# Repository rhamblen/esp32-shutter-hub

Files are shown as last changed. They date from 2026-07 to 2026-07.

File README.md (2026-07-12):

# ESP32 Smart Shutter Hub

A compact, DIY smart-home controller that tilts existing internal plantation shutters with servo
actuators — behaving like a commercial product while staying small, cheap, mains-free (wired 5 V),
and fully local. One wall-mounted **hub** drives a configurable number of shutters (initially four
in the Front Room) and integrates natively with Apple Home and Home Assistant. Replaces a bulky
Zemismart JM36/JC601.

## Features

- **Hub architecture** — one ESP32 drives all shutters via a PCA9685; simple MG90D actuator modules.
- **Variable shutter count** — 1 to 4, by configuration only (no firmware change).
- **Apple HomeKit** — HomeSpan bridge exposes each shutter as its own Window Covering accessory.
- **Home Assistant** — one `cover.*` per shutter via MQTT discovery, plus lux/position sensors.
- **Local web UI** — control, per-shutter calibration, and OTA at `http://shutter-hub.local`.
- **Wiring at a glance** — an Info-page table of every device, its I²C bus, pins, address and channel.
- **Per-shutter calibration** — closed/open limits + named favourites (Privacy, Daylight) in µs.
- **Solar heat protection** — VEML7700 sunlight monitoring with configurable trip/clear thresholds.
- **Manual-override handling** — automation backs off for 2 h after a manual move.

## How it works

System architecture

One ESP32-D hub speaks to Apple Home (HomeSpan) and Home Assistant (MQTT) over WiFi, and drives the
servos through a PCA9685. A VEML7700 light sensor feeds the solar heat-protection logic. The number
of shutters is configuration, not code.

**Power & wiring**

Wiring schematic

**Actuator linkage**

Tilt linkage geometry

The tilt-rod drive is a four-bar linkage. **Build baseline (v0.9.2):** the owner's Zemismart-style
clip on the bottom slat is the crank; a tape-mounted MG90D on the rail's rear face → stock 20 mm
horn → M2×35 pushrod → clip pin drives all slats through 90°, everything hidden behind the panel
(rear pull-down). The servo cradle tapes on with no screws:

P1 servo cradle

Full kinematic analysis, an **animated simulator** (enter your shutter's measurements, get
collision/torque flags; v0.9.0–0.9.2 layouts are selectable presets), MG90D mount dimensions and
the 3D-print list live in the interactive design doc:
**<https://rhamblen.github.io/esp32-shutter-hub/tilt-linkage-design.html>**
(source: [docs/tilt-linkage-design.html](docs/tilt-linkage-design.html)).

**⬇ Download the 3D-print files** (right-click → Save, or just click — these are direct downloads):

| Part | 3MF | STL | Status |
| ---- | --- | --- | --- |
| P2 — slat-clip crank | [slat-clip-crank.3mf](https://github.com/rhamblen/esp32-shutter-hub/raw/main/cad/slat-hook/slat-clip-crank.3mf) | [slat-clip-crank.stl](https://github.com/rhamblen/esp32-shutter-hub/raw/main/cad/slat-hook/slat-clip-crank.stl) | ✅ ready — see [fitting notes](cad/slat-hook/README.md) |
| P1 — servo cradle | _pending_ | _pending_ | 📐 drawings only ([§7](https://rhamblen.github.io/esp32-shutter-hub/tilt-linkage-design.html)) |

Full parts list and print settings: **[cad/README.md](cad/README.md)**.

## Hardware (locked)

| Component | Choice | Default pins (ESP32-D) |
| --- | --- | --- |
| Controller | ESP32-D | — |
| Servo driver | PCA9685 (16-ch I2C, `0x40`) | `Wire` — SDA **GPIO21**, SCL **GPIO22** |
| Servos | MG90D digital metal-gear ×4 | PCA9685 **CH0–CH3** |
| Power | USB-C PD → AITRIP trigger (12 V) → XL4015 @ 5.1 V | — |
| Light sensor | VEML7700 (I2C, `0x10`) | `Wire1` — SDA **GPIO25**, SCL **GPIO26** |
| Linkage | M2 × 50 mm ball-link pushrod + printed arms | — |

By default the sensor sits on a **second, separate I2C bus** so a fault on its lead can never wedge
the servo bus ([ADR 0011](docs/decisions/0011-dedicated-sensor-i2c-bus.md)). It can also be told to
**share** the PCA9685's bus ([ADR 0012](docs/decisions/0012-selectable-sensor-i2c-bus.md)) — the only
option on chips with a single I2C controller, such as the ESP32-C3. Every pin above is
runtime-configurable and stored in NVS. Full map, including the ESP32-C3 proposal and the pins the
firmware rejects: **[docs/pinout.md](docs/pinout.md)**.

## Installation

Full step-by-step in **[docs/installation.md](docs/installation.md)**; everyday operation in
**[docs/user-guide.md](docs/user-guide.md)**. The short version:

1. **Flash once over USB.** Take the `esp32d-pca9685` assets from a
   [release](https://github.com/rhamblen/esp32-shutter-hub/releases) and write the `-full-` image to
   `0x0` plus the `-littlefs-` image — or build from source with
   `pio run -e esp32d-pca9685 -t upload && pio run -e esp32d-pca9685 -t uploadfs`.
   Flash the filesystem too; without it the hub serves only a bare OTA recovery page.
2. **Join your WiFi.** The hub raises a `Shutter-Hub-Setup` access point with a captive portal. Pick
   your 2.4 GHz network once — the credentials live in NVS and survive every future update.
3. **Open `http://shutter-hub.local`** and confirm a servo sweeps from the **Servo test** page.
4. **Define and calibrate each shutter** on the **Shutters** page: name it, assign its PCA9685
   channel, then set its closed/open endpoints and Daylight/Privacy favourites with the slow-run →
   stop → nudge transport. Everything else depends on this step.
5. **Point it at your MQTT broker** (**MQTT → Broker**, discovery on) and the covers, preset buttons
   and solar entities appear in Home Assistant by themselves. Optionally add the Lovelace card from
   [ha-card/](ha-card/), pair the HomeKit bridge from **System → HomeKit**, and set the trip/clear
   thresholds on the **Solar** page.

After the first flash every update goes over WiFi from the **OTA Update** page — settings,
calibration, and pairings are untouched.

## Status

**Current release `v0.7.2`.** In daily use: the web UI, per-shutter calibration, Home Assistant
control over MQTT, the Lovelace card, **Apple HomeKit pairing** (as of `v0.7.0`), and **solar heat
protection** driven by an ambient-light sensor. What's left for **v1.0.0** is the physical build-out —
enclosures, a PCB, and all four shutters mounted behind the wall (see the roadmap below).

Every shutter
defined in the web UI appears in HA as a native **`cover`** (open/close/stop + position 0–100) plus
six **`button`** entities (jog open/close, Daylight/Privacy recall + save) via MQTT discovery —
commands drive each shutter's own PCA9685 channel, **several simultaneously**, and retained
position/state topics track every move (web-UI moves included). The device interface is a
**LittleFS single-page app** (sidebar: Info · MQTT · Servo test · Shutters · System · OTA · Logs)
with a **live log stream** over WebSocket, a live per-shutter **MQTT topic map**, web
authentication, and a custom firmware+filesystem OTA updater. The servo backend is a **build
variant** — **direct GPIO** (one bench servo) or **PCA9685** (I2C multi-channel) — identified on
the Info/OTA screens and in the artifact names, with a persisted **speed slider** (5–120 °/s). The
**Shutters** page is per-blind calibration: a microsecond scrubber + transport controls (slow-run →
stop → frame-step nudge) set each blind's closed/open endpoints and Daylight/Privacy favourites,
all persisted in NVS. Servo positions are remembered across reboots/OTA so the first move slews
instead of snapping. A **Home Assistant Lovelace card** ([ha-card/](ha-card/)) gives a single tile
with group + per-shutter Open/Close/Daylight/Privacy and a manual position slider.
**Phase 5 (`v0.5.x`)** adds an **Apple HomeKit** bridge (HomeSpan): each shutter also appears in the
Home app as a **Window Covering**, configured on a new **System › HomeKit** tab (bridge name, setup
code, pairing QR). The bridge runs on its own task so it never interferes with servo control, and
reboot/OTA are driven by a reliable timer. **Status: working as of `v0.7.0`.** Pairing failed on the
author's hardware through v0.6.x; the root cause was finally found in v0.7.0 — HomeSpan 1.9.1's mDNS
hostname check uses a `sscanf("%m…")` conversion that **newlib-nano doesn't implement**, halting the
bridge before it advertised. With that patched, the bridge pairs and shutters **sync both ways**
(Home ↔ HA) — see [CHANGELOG.md](CHANGELOG.md).
**Phase 6 (`v0.6.0`)** adds **solar heat protection**: a **VEML7700** light sensor on its own I²C
bus drives a trip/clear state machine — when the sun stays above a threshold for a set dwell the
shutters move to a chosen preset, and a second threshold releases them. Both actions can be set to
**Do nothing**, a manual move suspends automation on that blind for 2 h, and a **simulate-lux
slider** lets the whole path be exercised from the Solar page. Lux, state, an automation switch and
two writable thresholds are published to Home Assistant.
**`v0.6.2`** makes the Info page a wiring check: a **Hardware & wiring** table naming every device,
its I²C bus (shared or dedicated), its pins, and its address or PCA9685 channel — plus HomeKit
status and a human-readable brightness percentage alongside raw lux.
**`v0.7.0`** makes **HomeKit pairing work** (see above), adds a bridge-health WARN watchdog, and
begins a log-level cleanup. Its fix is carried as a vendored HomeSpan patch under
[firmware/patches/](firmware/patches/). **`v0.7.1`** tidies that up — removes the investigation's
debug scaffolding and finishes the log-level cleanup (no behavioural change). **`v0.7.2`** fixes the
dashboard reading "not paired" after a reboot/OTA, and makes the servo-GPIO whitelist chip-aware so an
ESP32-C3 can no longer be configured onto a flash pin that bricks boot.
See [docs/project-plan.md](docs/project-plan.md) for the phased roadmap and [firmware/](firmware/)
to build/flash. Prebuilt bins ship on each
[release](https://github.com/rhamblen/esp32-shutter-hub/releases) — all four variants (ESP32-D, plus
ESP32-C3 as untested engineering builds): full (USB) and firmware (OTA), plus one shared LittleFS
filesystem image.

## Repo layout

| Path | Contents |
| ---- | --- |
| [docs/installation.md](docs/installation.md) | Full install guide — flash, WiFi, calibrate, HA, HomeKit, solar |
| [docs/user-guide.md](docs/user-guide.md) | Everyday operation, solar behaviour, recalibration, troubleshooting |
| [docs/pinout.md](docs/pinout.md) | GPIO map — ESP32-D defaults, ESP32-C3 proposal, rejected pins |
| [docs/project-brief.md](docs/project-brief.md) | Master engineering specification |
| [docs/project-plan.md](docs/project-plan.md) | Phased roadmap + status + open decisions |
| [docs/architecture.md](docs/architecture.md) | Principles, trade-offs, topology |
| [docs/inventory.md](docs/inventory.md) | Bill of materials + shutter facts |
| [docs/hardware-layout.md](docs/hardware-layout.md) | Breadboard build plan — placement, cuts, standoffs, cables |
| [docs/ha-lovelace-card.md](docs/ha-lovelace-card.md) | Lovelace card spec — entity model, config schema, layout |
| [docs/ai-context.md](docs/ai-context.md) | Cold-start map for the next AI session |
| [docs/decisions/](docs/decisions/) | Architecture Decision Records |
| [docs/diagrams/](docs/diagrams/) | Architecture, wiring, and linkage SVGs |
| [firmware/](firmware/) | ESP32 firmware (PlatformIO, Arduino Core) — build/flash/OTA |
| [ha-card/](ha-card/) | Home Assistant Lovelace operating card (custom element) |
| [hardware/](hardware/) | KiCad schematic / PCB + fabrication outputs |
| [cad/](cad/) | 3D-printer source + STL/STEP for enclosures & parts |
| [CHANGELOG.md](CHANGELOG.md) | Change history (Keep a Changelog + SemVer) |

## License & Legal

### License

This project is licensed under the MIT License — see the [`LICENSE`](LICENSE) file for details.

### Disclaimer

This is a DIY hardware project that drives mains-adjacent mechanical shutters with servos and a
custom power supply. **Use at your own risk** — you are responsible for the electrical safety and
mechanical integrity of anything you build from it. It is provided "as is", without warranty of any
kind. Apple Home integration is via the open-source [HomeSpan](https://github.com/HomeSpan/HomeSpan)
HomeKit library; this project is **not affiliated with, endorsed by, or condoned by Apple Inc.**

### Trademarks

- Apple, HomeKit, and Siri are trademarks of Apple Inc.
- ESP32 is a trademark of Espressif Systems (Shanghai) Co., Ltd.
- Home Assistant is a trademark of the Open Home Foundation.

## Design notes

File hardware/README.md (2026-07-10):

# Hardware — schematics & PCB

Circuit design source and fabrication outputs for the Shutter Hub.

## Contents

| File | Purpose |
| ---- | --- |
| `shutter-hub.kicad_sch` | KiCad schematic — complete ESP32-D circuit (power chain, I2C, servo driver, sensor) |
| `shutter-hub-schematic.svg` | Visual schematic — power chain, loads, wiring, critical build checklist |
| `shutter-hub-breadboard-layout.svg` | KiCad-style breadboard layout (plan view) — component placement, jumper/wire schedule W1–W13, connectors J1–J3, raised modules |

## Status

**Schematic complete** (`shutter-hub.kicad_sch`) for breadboard prototyping. **PCB layout and fabrication** are Phase 7. Currently, the working build is hand-wired on breadboard per Phases 1–6.

## Schematics & Drawings

Human-readable diagrams are in [`../docs/diagrams/`](../docs/diagrams/):

| Diagram | Purpose |
| --- | --- |
| [`wiring-schematic.svg`](../docs/diagrams/wiring-schematic.svg) | Power chain & signal routing (USB-C → XL4015 → ESP32-D, PCA9685, VEML7700) |
| [`system-architecture.svg`](../docs/diagrams/system-architecture.svg) | Overall hub architecture and component relationships |
| [`breadboard-plan.svg`](../docs/diagrams/breadboard-plan.svg) | Development breadboard layout (GPIO, I2C, power) |
| [`hub-build-overview.svg`](../docs/diagrams/hub-build-overview.svg) | Physical assembly and enclosure overview |
| [`standoff-mounting.svg`](../docs/diagrams/standoff-mounting.svg) | PCB mounting points and standoff placement |
| [`cable-loom.svg`](../docs/diagrams/cable-loom.svg) | Servo rail and sensor cabling layout |
| [`rail-cuts-bridges.svg`](../docs/diagrams/rail-cuts-bridges.svg) | Servo power rail distribution |

See [`../docs/hardware-layout.md`](../docs/hardware-layout.md) for detailed component placement and [`../docs/pinout.md`](../docs/pinout.md) for GPIO/I2C pin mapping.

## Design intent (see `../docs/project-brief.md` §3–4)

```
USB-C PD → AITRIP trigger (12 V) → XL4015 (5.1 V) ─┬─ ESP32-D VIN
                                                   ├─ PCA9685 V+
                                                   └─ servo rail (+1000–2200 µF) → MG90D ×N
ESP32-D I2C (GPIO21 SDA / GPIO22 SCL) ─┬─ PCA9685 (0x40) → CH0..CHn
                                       └─ VEML7700 (0x10)
Single-point common ground.
```

Design rules to honour on the PCB: keep the servo-power copper wide (2–3 A), place the bulk
capacitor next to the PCA9685 V+, keep the ESP32 rail decoupled from servo current, and leave
airflow / vent area over the XL4015 (see [ADR 0003](../docs/decisions/0003-power-chain-xl4015-pca9685.md)).

> Status: **to be produced.** A hand-wired/protoboard build (Phases 1–6) precedes the PCB
> (Phase 7). Until then this folder holds the wiring diagram only.

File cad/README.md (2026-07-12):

# CAD — 3D-printed parts

Enclosures and mechanical parts for the hub and the per-shutter actuator modules.

## ⬇ Download print files

Direct download links (click to save — no GitHub account needed). Both `.3mf` (with print
metadata) and `.stl` are provided for each ready part.

| Part | 3MF | STL | Status |
| ---- | --- | --- | --- |
| **P2 — slat-clip crank** | [⬇ .3mf](https://github.com/rhamblen/esp32-shutter-hub/raw/main/cad/slat-hook/slat-clip-crank.3mf) | [⬇ .stl](https://github.com/rhamblen/esp32-shutter-hub/raw/main/cad/slat-hook/slat-clip-crank.stl) | ✅ ready to print |
| **P1 — servo cradle** | _pending_ | _pending_ | 📐 drawings only ([servo-cradle-p1.svg](../docs/diagrams/servo-cradle-p1.svg)) |

> Tip: on the GitHub file page for any part, the **Download raw file** button (top-right ⬇ icon)
> saves it too. To grab everything at once, use the green **Code → Download ZIP** on the repo home.

## Contents (as produced)

| Path | Part | Notes |
| ---- | ---- | ----- |
| `hub-enclosure/` | Wall-mounted hub box | Compartments for AITRIP trigger, XL4015 (vent slots above), ESP32-D, PCA9685; servo-cable exits; VEML7700 light window |
| `actuator-module/` | P1 — servo cradle (**tape-mount, drawings done; 3MF pending**) | MG90D case bonded in with a 2nd VHB strip (no screws, tabs unused); plate 40×34×2.4 VHB'd to the rail rear face; side walls stop short of the tabs; 4 mm cable gallery + open lay-in slot. Axis (+24.7,−49). Drawings: [servo-cradle-p1.svg](../docs/diagrams/servo-cradle-p1.svg) · design doc §7 |
| `slat-hook/` | P2 — slat-clip crank (**produced**: `slat-clip-crank.3mf`) | Zemismart-style sleeve clip + added drill boss; wedges onto the 8 mm slat, M2 ball stud drilled 12 mm from the rear edge → pin 26.6 mm @ −16°; see [slat-hook/README.md](slat-hook/README.md) |
| `servo-arm/` | P3 — 22 mm servo arm (optional) | Only for the 34 mm-crank torque variant; stock 20 mm horn is the baseline |
| `servo-test-bracket/` | Phase 0 proving rig | Temporary mount to run the force test |

Each part folder holds **editable source** (FreeCAD `.FCStd` / Fusion `.f3d` / OpenSCAD `.scad`)
**and** exported **`.stl`** (print-ready) plus **`.step`** (interchange). Keep source + exports
together so the parts stay editable.

## Key dimensions (see `../docs/tilt-linkage-design.html` — interactive design doc)

- Servo: MG90D case 22.8 × 12.2 × 28.5 mm; tabs 32.5 mm span, Ø2.2 holes @ 27.5 mm centres;
  shaft axis ≈6 mm from the front face; 21T Ø4.8 spline. Verify with calipers — clones vary ±0.3 mm.
- Linkage (v0.9.1 four-bar): stock 20 mm horn + **front-edge** slat hook (pin 24 mm on the
  front-edge line; 06:00 closed → 03:00 open) + **M2×25** ball-link pushrod at **46 mm**
  hole-to-hole. ~114° servo sweep → 90° slat travel, jam margin 11.3 mm, torque ratio ≤0.85.
- **Build baseline (v0.9.2):** the owner's clip drives a **rear pull-down** layout — servo cradle
  tape-mounted on the rail's rear face, axis **(+24.7, −49)**, stock 20 mm horn, M2×35 pushrod at
  58 mm, clip pin 26.6 @ −16°. ~132° sweep, jam margin 9.3 mm, ratio ≤0.77, rear-most 44.7 mm.
  (v0.9.0/0.9.1 variants retained in the design doc as presets.)
- Shutter geometry: frame/rail thickness **28 mm (measured)**; still to measure: rocker radius
  R ≈ 36 mm, slat pitch ≈ 63 mm, rail top ≈ 45 mm below the bottom pivot, rear depth ≥ 43 mm.

[`../docs/diagrams/linkage-geometry.svg`](../docs/diagrams/linkage-geometry.svg) shows the
three-pose geometry (closed / mid / open), generated from the same solver. The HTML design doc is
authoritative and served live at
<https://rhamblen.github.io/esp32-shutter-hub/tilt-linkage-design.html>.

> Status: **to be produced.** Phase 0 prints the servo-test-bracket + shutter-arm first; final
> enclosures come in Phase 7.

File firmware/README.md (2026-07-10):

# Firmware — ESP32 Smart Shutter Hub

PlatformIO project (Arduino Core, `esp32dev`). Structural reference:
[HomeKey-ESP32](https://github.com/rednblkx/HomeKey-ESP32). See
[../docs/project-plan.md](../docs/project-plan.md) for the phased roadmap.

## What this version does (v0.7.2)

On-device WiFi setup, advertises `shutter-hub.local` over mDNS, and serves a
**single-page web UI from LittleFS** (sidebar: Info · MQTT · Servo test · Shutters ·
Solar · System · OTA · Logs) over a JSON/REST API. A **live log stream** runs over
WebSocket (`/ws/logs`). The **Info** page carries a **Hardware & wiring** table (v0.6.2)
— every device, its I²C bus, pins, and address or channel — a read-only mirror of
settings made on the other pages. **MQTT (Phase 4)**: every shutter defined on the Shutters page becomes a
native **Home Assistant `cover`** (open/close/stop + position 0–100) plus **six
`button` entities** (jog open/close, Daylight/Privacy recall, save Daylight/Privacy)
via MQTT discovery — commands drive each shutter's own PCA9685 channel, **several
simultaneously** (ADR 0010), and retained `position`/`state` topics track every move,
web-UI ones included. The MQTT page's **Topics** tab shows the live per-shutter topic
map. Custom **OTA** flashes firmware and/or the LittleFS image. The **Servo test** page
is a low-level bench diagnostic with a persisted **speed slider** (5–120 °/s); the
**Shutters** page (Phase 2) is per-blind **calibration**: a microsecond scrubber +
transport controls (slow-run → stop → frame-step nudge) snapshot each blind's
closed/open endpoints and Daylight/Privacy favourites, all persisted in NVS (survives a
filesystem OTA). The servo backend is a **build variant** — `-direct` (one servo off a
GPIO, bare ESP32) or `-pca9685` (I2C multi-channel); the web UI adapts to whichever
it's running.

**Solar heat protection (Phase 6, v0.6.0–v0.6.2)**: a **VEML7700** drives a trip/clear
state machine that moves the shutters to a chosen preset in strong sun. Its I²C bus is a
setting — its own `Wire1` (default) or shared with the PCA9685 (ADR 0011/0012). The
**Solar** page has a **simulate-lux slider**, so the whole feature is exercisable with no
sensor fitted. Lux, a 0–100 % brightness figure, solar state, an automation switch and two
writable lux thresholds are published to Home Assistant.

**Apple HomeKit (Phase 5, v0.5.x–v0.7.2)**: a HomeSpan bridge exposes each shutter as a Window
Covering, configured under **System → HomeKit**. It runs on its own FreeRTOS task, so HAP
never stalls the servo loop. **Pairing works** (fixed v0.7.0 — HomeSpan 1.9.1's `sscanf("%m…")`
hostname check isn't supported by newlib-nano; patched under [`patches/`](patches/)). The bridge
is discovered, pairs, and syncs both ways with Home Assistant. See
[../docs/project-plan.md](../docs/project-plan.md) Phase 5.

## WiFi setup (on-device — no credentials in the binary)

On first boot (and after **Change WiFi**) the hub becomes an access point
**`Shutter-Hub-Setup`** with a captive portal:

1. Join the `Shutter-Hub-Setup` network from a phone or laptop.
2. The captive portal opens (or browse to `http://192.168.4.1`). Pick your WiFi
   and enter the password.
3. The hub saves the credentials to **NVS** and reconnects. NVS is a separate
   flash partition, so the credentials **survive OTA updates** — you only do this
   once.

This uses [WiFiManager](https://github.com/tzapu/WiFiManager) — the Arduino-native
version of the SoftAP + captive-portal pattern in
[HomeKey-ESP32](https://github.com/rednblkx/HomeKey-ESP32). Because nothing is
compiled in, the same prebuilt bin works on anyone's network. To change networks
later, use **System → WiFi** (scan/connect in place); **Reset WiFi** in the System
page's Quick Actions reboots back into this setup portal.

## Build

From **v0.3.0** the firmware ships as **variants** = *board × servo backend* (see
[../docs/decisions/0008-build-variants.md](../docs/decisions/0008-build-variants.md)).
Each variant is a PlatformIO env carrying a `FW_VARIANT` id that shows on the
Dashboard/OTA screens and names the artifacts:

| Env | Board | Servo backend | Status |
| --- | ----- | --- | --- |
| `esp32d-direct` | ESP32-D | direct GPIO (ESP32Servo) | active |
| `esp32d-pca9685` | ESP32-D | PCA9685 I2C (Adafruit PWM) | **active, default** |
| `esp32c3-direct` | ESP32-C3 | direct GPIO | deferred |
| `esp32c3-pca9685` | ESP32-C3 | PCA9685 I2C | deferred |

```
pio run                            # builds the default env (esp32d-pca9685)
pio run -e esp32d-direct           # ESP32-D, direct-GPIO servo
pio run -e esp32d-pca9685          # ESP32-D, PCA9685
pio run -e esp32c3-pca9685         # ESP32-C3 (deferred; build explicitly if needed)
```

Prebuilt bins are collected in [`dist/`](dist/). From **v0.2.0** a release ships
**three bins per variant** (the web UI now lives in `data/`):

| Scope | File | Use | Since |
| ----- | ---- | --- | ----- |
| Per variant | `shutter-hub-<variant>-full-vX.Y.Z.bin` | first USB flash, merged at `0x0` | now |
| Per variant | `shutter-hub-<variant>-ota-vX.Y.Z.bin` | OTA page → **Upload Firmware** | now |
| Per **board** | `shutter-hub-esp32d-littlefs-vX.Y.Z.bin` | OTA page → **Upload LittleFS** | **v0.2.0** |

Build the filesystem image with `pio run -e <variant> -t buildfs` →
`.pio/build/<variant>/littlefs.bin`. **Flash it alongside the firmware** — without it
the device serves an embedded recovery page (OTA upload only). The LittleFS image is
**identical across variants** (the Servo-test page adapts at runtime), so one filesystem
bin per version is enough — only the firmware differs per variant.

_ESP32-C3 bins are not built or released yet._

## First flash (USB — one time only)

After this, every update goes over WiFi (see OTA below).

**Option A — PlatformIO, board on USB:**
```
pio run -e esp32d-pca9685 -t upload   # auto-detects the port; monitor with:  pio device monitor
```

**Option B — single merged image (NodeMCU-PyFlasher / esptool):**
Flash the `-full-` image for your variant at offset `0x0`:
```
esptool --chip esp32 write_flash 0x0 dist/shutter-hub-esp32d-pca9685-full-v0.7.2.bin
```
In NodeMCU-PyFlasher: select the `...-full-...bin`, address `0x0`, flash.

> Merge recipe (how the `-full-` image is made): `esptool --chip esp32 merge-bin`
> with bootloader + partitions + boot_app0 + firmware. The ESP32-D bootloader sits at
> `0x1000` and the app at `0x10000`.

## Update over the air (every time after the first)

The **OTA Update** page at `http://shutter-hub.local/` is a custom updater: it shows the
installed version, chip, last flash, and two uploaders — **Firmware** and
**Filesystem (LittleFS)** — with an upload log.

1. Build new bins: `pio run` (firmware) and `pio run -t buildfs` (filesystem).
2. **Upload Firmware** with the app bin; **Upload LittleFS** when the web UI (`data/`)
   changed. Upload the filesystem first if both changed, then the firmware (which reboots).
3. The board reboots into the new build — your saved WiFi and settings are untouched
   (they live in NVS, not the app/filesystem partitions).

## Layout

```
firmware/
├─ platformio.ini              board targets + libraries + build flags
├─ include/                    module headers (*.h)
├─ data/                       LittleFS web UI (index.html, style.css, app.js, qrcode.min.js)
├─ src/
│  ├─ main.cpp                 thin entry point — wires the modules together
│  ├─ AppConfig.cpp            persisted settings: device, servo, MQTT, auth, HomeKit, solar (NVS)
│  ├─ Diagnostics.cpp          logging + log ring buffer + WS sink, /info
│  ├─ WiFiSetup.cpp            WiFiManager AP + captive portal
│  ├─ WebUI.cpp                static SPA + JSON API + /ws/logs + mDNS
│  ├─ Ota.cpp                  custom firmware + LittleFS OTA
│  ├─ ServoController.cpp      multi-slot µs driver, backend = GPIO | PCA9685
│  ├─ Shutters.cpp             per-blind definitions + calibration (NVS)      [Phase 2]
│  ├─ Mqtt.cpp                 HA covers/buttons/solar + discovery + state    [Phase 4/6]
│  ├─ HomeKit.cpp              HomeSpan bridge (pairing works)                [Phase 5]
│  ├─ LightSensor.cpp          VEML7700 driver (selectable I²C bus)           [Phase 6]
│  └─ SolarLogic.cpp           trip/clear state machine + manual override     [Phase 6]
├─ dist/                       prebuilt release artifacts (bins gitignored; attached to releases)
└─ README.md
```

The web UI is static files in `data/` (LittleFS), served by `WebUI` over a JSON API +
WebSocket; the firmware falls back to an embedded recovery page if the FS image is
missing (see ADR 0004/0005). `WebUI` is named that (not `WebServer`) to avoid clashing
with the Arduino core's `WebServer.h` that WiFiManager includes.

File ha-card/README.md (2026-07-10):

# shutter-hub-card — Home Assistant Lovelace card

An operating tile for the ESP32 Shutter Hub: 1–6 named shutters side by side, the four
blind states (**Open · Close · Daylight · Privacy**) and a **manual position slider**,
applied to **all shutters at once** or to **one selected shutter**.

No build step — a single plain custom element (`shutter-hub-card.js`), registered as a
Lovelace resource. Full design rationale in
[../docs/ha-lovelace-card.md](../docs/ha-lovelace-card.md) and
[../docs/decisions/0007-ha-lovelace-card.md](../docs/decisions/0007-ha-lovelace-card.md).

## What it does

- **Group mode (default)** — every configured shutter shown as a tile (a slat glyph whose
  angle tracks position, its name, and state). The button bar and slider act on **all**
  shutters.
- **Individual mode** — tap a tile to scope the buttons and slider to just that shutter;
  tap it again, or **Select all**, to return to the group.
- **Four states** — Open / Close drive the cover to its calibrated limits; Daylight /
  Privacy press the saved-preset buttons.
- **Manual position** — the slider commands an arbitrary position (0–100 %) via
  `cover.set_cover_position`, for any angle that isn't one of the four presets.
- **Stop** — halts an in-flight move.

## Entities

Binds to the MQTT-discovered entities (one hub device):

| Entity | Role |
| --- | ---- |
| `cover.<hub>_<id>` | open / close / stop / position |
| `button.<hub>_<id>_daylight` | recall the saved Daylight preset |
| `button.<hub>_<id>_privacy` | recall the saved Privacy preset |

The two button ids default to the cover id with `cover.` → `button.` and a
`_daylight` / `_privacy` suffix; override per shutter with `daylight:` / `privacy:` if
your naming differs.

### Solar heat protection (optional)

If the hub has a VEML7700 fitted, three more entities can be bound. Supply any of them and the
group header grows a **live light caption** and an **automation toggle**; omit them all and the
card renders exactly as before, so no-sensor installs are unaffected.

| Config key | Entity | Role |
| --- | --- | ---- |
| `solar_switch` | `switch.<hub>_solar_automation` | Turns the trip/clear automation on or off |
| `solar_lux` | `sensor.<hub>_light_level` | Raw illuminance in lux — what the card's caption shows |
| `solar_state` | `sensor.<hub>_solar_state` | `idle` · `counting-trip` · `tripped` · `counting-clear` |

**Why the caption reads lux and not a percentage.** The hub also publishes
`sensor.<hub>_brightness` (0–100 %), which is friendlier to read but is **display-only**, and this
card does not use it. It is a logarithmic restatement of the same reading —
`20 × log10(lux)`, one lux decade per 20 points:

| Brightness | Lux | Roughly |
| --- | --- | --- |
| 0 % | 1 | dark room |
| 20 % | 10 | dim |
| 40 % | 100 | lit room |
| 54 % | ~500 | bright room |
| 60 % | 1 000 | overcast, by a window |
| 80 % | 10 000 | overcast daylight |
| 100 % | 100 000 | full sun |

A linear percentage of the sensor's 120 000 lx full scale was rejected: it reads 0 % at every
indoor level and only moves in direct sun. The log curve fixes that, but it compresses the
30 000–60 000 lx band where the trip and clear thresholds live — the defaults land at 96 % and
90 %, six points apart — so it can't be used to set or reason about thresholds, and it isn't
cleanly invertible. **The state machine trips on raw lux**; raw lux is what the caption shows and
what Home Assistant's long-term statistics record. Treat brightness as a human-readable gauge,
never as an automation input.

```yaml
solar_switch: switch.shutter_hub_solar_automation
solar_lux: sensor.shutter_hub_light_level
solar_state: sensor.shutter_hub_solar_state
```

## Install

Two paths — both end with the same dashboard card.

**Inline resource (what this repo deploys):** register `shutter-hub-card.js` as a
dashboard resource of type `module` (the HA config API accepts inline module content), then
add the card below. No file hosting needed.

**Filesystem:** copy `shutter-hub-card.js` to `/config/www/shutter-hub-card.js`, add a
Lovelace resource `URL /local/shutter-hub-card.js`, type **JavaScript Module**, hard-refresh.

## Card config

```yaml
type: custom:shutter-hub-card
title: Shutters
shutters:                       # 1–6 entries, order = display order
  - entity: cover.shutter_hub_shutter_1
    name: Left                  # optional; defaults to the cover's friendly name
  - entity: cover.shutter_hub_shutter_2
    name: Right
```

## Not included (Phase 8, optional)

**Calibration / config card** — setting raw-µs positions, the full-open/close travel
endpoints, and *saving* into the four slots — is deliberately a **separate card**, planned
as **optional Phase 8** in [the project plan](../docs/project-plan.md). It needs firmware
commands that don't exist yet (an absolute *go-to-µs*, raw-µs readback, and `save:open` /
`save:close`), documented in [../docs/ha-lovelace-card.md](../docs/ha-lovelace-card.md) §4.
Until then, calibrate in the hub's web UI; this card operates the shutters HA already
knows how to drive.

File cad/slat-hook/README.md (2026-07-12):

# P2 — slat-clip crank

**⬇ Download:** [slat-clip-crank.3mf](https://github.com/rhamblen/esp32-shutter-hub/raw/main/cad/slat-hook/slat-clip-crank.3mf)
· [slat-clip-crank.stl](https://github.com/rhamblen/esp32-shutter-hub/raw/main/cad/slat-hook/slat-clip-crank.stl)
(identical geometry; use whichever your slicer prefers)

The Zemismart-style rod-to-slat coupler (`clip1.3mf`) with a **solid drill boss** added under the
bottom strap. Clipped onto the bottom slat it becomes the linkage's crank; an M2 ball-stud through
the boss is the drive pin. Two closed shells in one object — every slicer unions them.

## How the original part works (measured from the mesh)

- **Sleeve**: mouth 8.35 mm, ~67 mm deep, tapering toward a solid nose. An 8 mm slat wedges tight
  where the taper reaches 8.0 (≈12 mm short of the nose) — the taper *is* the retention, so the
  geometry is left untouched.
- **Fin jaw** (5.0 mm gap): factory feature that snaps onto the tilt-rod bar. **Unused here** — the
  clip must sit ≥10 mm inboard of the rod's plane. Leave it or trim it.
- 12 mm wide along the slat; straps 1.35 / 1.75 mm thick.

## Fitting (rear pull-down layout)

1. Push the clip onto the bottom slat **from the rear (window) edge**, ≥10 mm inboard of the
   tilt-rod staple, until it wedges. Nose ends up near the rear edge, fin at the front.
2. Mark the boss **12 mm in from the slat's rear edge**, at the boss's mid-height.
3. Drill Ø1.8 through the boss along the slat direction; fit the M2 ball stud (self-tap), ball on
   the side facing the servo.

Ball centre lands ≈ **26.6 mm radius, −16° phase** from the slat pivot.

## Matching linkage (solved for this pin; slats close rear-edge-up)

| Element | Value |
| --- | ----- |
| Servo arm | stock **20 mm** horn |
| Pushrod | **M2×35 at 58 mm** hole-to-hole (any owned rod 46–61 works — drop the servo 1 mm per 1 mm of extra rod) |
| Servo axis | **(+21, −49)** from the bottom slat pivot — cradle on the rail's rear face, 1 mm plate |
| Sweep | ~129° of 180° → 90° slat travel, near-linear |
| Jam margin / torque | 9.9 mm / ratio ≤0.79 → ≈2.8 kg·cm at the slats |
| Envelope | x ∈ [+7, +41] — fully behind the panel, nothing on the room side |

Verify against your measurements in the live simulator (crank 26.6 / phase −16):
<https://rhamblen.github.io/esp32-shutter-hub/tilt-linkage-design.html>

## Load-path note

The clip was designed to be dragged by the rod, not to drive the slat. If it slips on the slat
under torque, add two grub-screw dimples through the straps or a drop of silicone in the sleeve.

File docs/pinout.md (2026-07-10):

# Pinout Summary

Every GPIO the hub uses, per board. The **ESP32-D** table is authoritative — it is what the firmware
actually defaults to today. The **ESP32-C3** table is a *proposal*: the C3 build variants compile,
but their pin map has never been revisited and a hardware limit still blocks them. See
[C3 status](#esp32-c3-status--not-ready) before trusting it.

On the C3 the light sensor **shares the PCA9685's I²C bus** — it has only one I²C controller, so the
dedicated-bus default is clamped to shared ([ADR 0012](decisions/0012-selectable-sensor-i2c-bus.md)).

All I²C and servo pins are **configurable at runtime** (web UI → Servo test / Solar) and persisted in
NVS. The values below are the compiled-in defaults a factory-reset device comes up with.

To read what a **running** hub actually has — which device on which bus, on which pins, at which
address or channel, and whether it is answering — open its **Info** page and look at the
**Hardware & wiring** table (v0.6.2+). This page is the authority for a factory-fresh device; that
table is the authority for a configured one.

---

## ESP32-D (ESP32-WROOM DevKit) — the locked, shipping board

PlatformIO `board = esp32dev`; variants `esp32d-pca9685` (the real hub) and `esp32d-direct` (a
single-servo bench build).

| GPIO | Function | Used by | Default set in |
| ---- | --- | --- | --- |
| **21** | I²C **SDA** — `Wire`, servo bus | PCA9685 @ `0x40` | `AppConfig.cpp` `g_i2cSda` |
| **22** | I²C **SCL** — `Wire`, servo bus | PCA9685 @ `0x40` | `AppConfig.cpp` `g_i2cScl` |
| **25** | I²C **SDA** — `Wire1`, sensor bus | VEML7700 @ `0x10` | `AppConfig.cpp` `g_lsSda` |
| **26** | I²C **SCL** — `Wire1`, sensor bus | VEML7700 @ `0x10` | `AppConfig.cpp` `g_lsScl` |
| **13** | Servo signal (**`-direct` builds only**) | one MG90D, LEDC-backed | `AppConfig.cpp` `g_servoPin` |
| 0 | Boot / recovery strapping | bootloader | — |
| 34 | *(optional, not implemented)* servo-rail voltage monitor | ADC1 | — |

Servos on a PCA9685 build hang off the **driver**, not the ESP32: **CH0–CH3 → shutters 1–4**, assigned
per shutter on the web UI's **Shutters** page.

**Two I²C buses, by default.** The PCA9685 (`0x40`) and VEML7700 (`0x10`) have distinct addresses
and *could* share one bus. By default they don't: the sensor gets its own `Wire1` so a damaged sensor
lead — a long run to a window — can never wedge the servo bus and strand the shutters
([ADR 0011](decisions/0011-dedicated-sensor-i2c-bus.md)). The bus is selectable on the **Solar** page
([ADR 0012](decisions/0012-selectable-sensor-i2c-bus.md)); in **shared** mode the sensor uses GPIO21/22
and these two pins are free.

### Pins the firmware will refuse

`ServoController::validGpio()` accepts only:

```
0 1 2 3 4 5 12 13 14 15 16 17 18 19 21 22 23 25 26 27 32 33
```

Excluded, and why:

| GPIO | Why it is rejected |
| ---- | --- |
| 6–11 | Wired to the SPI flash chip — using them bricks the boot |
| 34–39 | **Input-only.** They cannot drive a servo signal or an open-drain I²C line |
| 20, 24, 28–31 | Not bonded out on the WROOM module |

The same whitelist validates the servo signal pin *and* the I²C pins, because I²C needs
bidirectional-capable pins. This is why the Solar page warns you off GPIO34–39.

---

## ESP32-C3 (ESP32-C3-DevKitM-1) — proposed, deferred

PlatformIO `board = esp32-c3-devkitm-1`; variants `esp32c3-direct`, `esp32c3-pca9685`. Not in
`default_envs`.

The C3 is a different chip with a different pinout — only **GPIO0–21 exist**, and several are spoken
for. A workable map *would* be:

| GPIO | Proposed function | Note |
| ---- | --- | ---- |
| **8** | I²C SDA — servo bus (PCA9685) | Arduino core's default `SDA` on this board; also a strapping pin |
| **9** | I²C SCL — servo bus (PCA9685) | Arduino core's default `SCL`; also the BOOT strapping pin |
| **3** | Servo signal (`-direct` builds) | ADC1 capable; otherwise unencumbered |
| 8 / 9 | I²C sensor bus — **shared** with the PCA9685 | No `Wire1` on this chip; the VEML7700 (`0x10`) rides the servo bus alongside the PCA9685 (`0x40`) |

Reserved on the C3, do not use:

| GPIO | Reserved for |
| ---- | --- |
| 11 | `VDD_SPI` |
| 12–17 | In-package SPI flash |
| 18, 19 | USB-Serial-JTAG (D− / D+) — the programming and console port |
| 20, 21 | UART0 RX / TX |
| 2, 8, 9 | Strapping pins — must be left in a sane state at boot |

That leaves roughly **GPIO0–7 and 10** genuinely free.

### ESP32-C3 status — not ready

All four envs compile clean today (`esp32c3-pca9685` links at 89.5 % flash, `esp32c3-direct` at
90.1 %). One of the two blockers below is **fixed as of v0.6.1**; the other still stands.

1. ~~**Solar heat protection cannot work on the C3.**~~ **Fixed in v0.6.1**
   ([ADR 0012](decisions/0012-selectable-sensor-i2c-bus.md)). A dedicated sensor bus needs a second
   I²C controller — the ESP32-D has two (`SOC_I2C_NUM == 2`), the C3 has one. The Arduino core
   declares `Wire1` unconditionally, so the C3 build linked fine and then failed *silently* at
   runtime (`i2cInit(1,…)` → `ESP_ERR_INVALID_ARG`), showing a permanent "not detected".
   The sensor bus is now a **setting**: on a one-controller chip the dedicated preference is clamped
   to **shared** (the VEML7700 rides the PCA9685's `Wire`), and the Solar page disables the dedicated
   option and says why. Solar works on the C3 — at the cost of the fault isolation ADR 0011 bought.
2. **The GPIO whitelist is now chip-aware (fixed v0.7.2).** `validGpio()` was an ESP32-D whitelist
   that, on a C3, accepted GPIO25/26/27/32/33 (which **don't exist**) and GPIO12–17 (the **SPI flash**
   → driving them bricks boot). It's now `#if CONFIG_IDF_TARGET_ESP32C3`: the C3 build offers only
   `{0–10, 18–21}` and refuses the flash pins, so a servo/I²C pin can no longer be set to a bricking
   GPIO. The remaining C3 caveat is the LEDC channel count below.

Also worth knowing: the C3 has **6 LEDC channels** to the ESP32-D's 16, capping a `-direct` build's
servo count; and at ~90 % flash there is little headroom left for HomeSpan to grow into.

The C3 bricking footgun is closed, but the C3 is still **not verified on real hardware** — its bins
ship attached to releases as clearly-flagged **untested engineering builds**, not proven firmware.

---

## Changing the defaults

Nothing here needs a rebuild. The web UI writes all of it to NVS, where it survives OTA:

| Pins | Where |
| ---- | ----- |
| Servo-bus SDA / SCL (PCA9685) | **Servo test** page |
| Servo signal GPIO (`-direct`) | **Servo test** page |
| Sensor-bus SDA / SCL (VEML7700) | **Solar** page → Sensor card |
| PCA9685 channel per shutter | **Shutters** page |

**System → Quick Actions → Reset config** returns every one of them to the compiled-in defaults in
the tables above.

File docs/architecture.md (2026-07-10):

# Architecture

Design principles, key trade-offs, and topology. Companion to
[project-brief.md](project-brief.md).

## Design principles

- **Hub-centric, not per-shutter controllers.** One ESP32 hub drives many dumb servo actuators.
  Fewer parts, one OTA target, one web UI, genuine synchronisation. (ADR 0001.)
- **Local first.** Full function without cloud: local WiFi, local web UI, local HA, local HomeKit.
- **Configuration over programming.** Shutter count, names, calibration, favourites, thresholds,
  WiFi, MQTT, OTA are all data. Firmware iterates a `shutters[]` array — no code change to add or
  remove a shutter.
- **Commercial-style UX.** Users see Open/Close/Position %/Daylight/Privacy — never servo angles
  or µs values.
- **Precision tilt actuator, not a blind motor.** The job is repeatable slat rotation of a
  lightweight assembly, quietly, in a compact package — not lifting weight.

## Key trade-offs

| Choice | Alternative | Why chosen | ADR |
| --- | --- | --- | --- |
| Central hub | 4 independent ESP32 nodes | Shutters share a room; short loom; 4× fewer parts; true sync | 0001 |
| MG90D | MG90S / DS3235 | Digital accuracy; huge torque margin for lightweight slats; DS3235 oversized | 0002 |
| XL4015 5.1 V | LM2596 | Servo peak 2–3 A vs LM2596's realistic ~2 A; XL4015 gives margin | 0003 |
| PCA9685 driver | Direct ESP32 PWM | Clean multi-servo drive off one I2C bus, easy channel expansion | 0003 |
| Custom firmware (HomeSpan+MQTT) | ESPHome | Keeps native HomeKit + custom smooth motion + calibration UI + OTA | 0004 |
| Pushrod + ball link | Direct servo-to-rod coupling | Tolerates misalignment; force off the gear train; easy install/removal | — |

## Hardware topology

```
USB-C PD → AITRIP trigger (12V) → XL4015 (5.1V) ─┬─ ESP32-D VIN
                                                 ├─ PCA9685 V+
                                                 └─ servo rail (+ 1000–2200µF) → MG90D ×N
ESP32-D I2C  Wire  (GPIO21/22) ── PCA9685 (0x40) ── CH0..CHn → servos
ESP32-D I2C  Wire1 (GPIO25/26) ── VEML7700 (0x10)   ← own bus by default (ADR 0011);
                                                      selectable to share Wire (ADR 0012)
Common ground single-point.
```

## Data sources / integration surfaces

- **HomeKit:** HomeSpan bridge, one Window Covering accessory per shutter. **Built, but pairing is
  unresolved — see [project-plan.md](project-plan.md) Phase 5.**
- **Home Assistant:** MQTT discovery, one `cover.*` per shutter + six `button`s, plus lux,
  brightness-%, solar-state, an automation switch and two writable lux thresholds.
- **Web:** ESPAsyncWebServer serving a LittleFS single-page app at `shutter-hub.local` — sidebar
  Info · MQTT · Servo test · Shutters · Solar · System (incl. WiFi + HomeKit) · OTA · Logs, over a
  JSON/REST API plus a `/ws/logs` WebSocket.
- **Config store:** **all settings live in NVS (Preferences)** — device identity, WiFi, MQTT, web
  auth, shutter definitions, calibration, favourites, HomeKit, solar. **LittleFS holds only the web
  assets.** The split is deliberate: a filesystem OTA reflashes the UI without touching a single
  setting (ADR 0005).

## Known gotchas

- **Servo inrush.** All 4 MG90D moving together spike current; stagger start-up in firmware, keep
  the bulk cap, keep ESP32 on the buck rail (not through the board), vent the XL4015.
- **Set XL4015 to 5.1 V before connecting anything** — measure with a meter first.
- **Two I2C buses by default; the sensor's bus is a setting.** PCA9685 (0x40) and VEML7700 (0x10)
  *could* coexist on one bus — distinct addresses, no clash — but by default the sensor gets its own
  `Wire1` (GPIO25/26) so a damaged sensor lead can't wedge the servo driver
  ([ADR 0011](decisions/0011-dedicated-sensor-i2c-bus.md)). It can be switched to share `Wire`
  ([ADR 0012](decisions/0012-selectable-sensor-i2c-bus.md)) — which is the **only** option on an
  ESP32-C3, whose single I2C controller can't host a second bus. GPIO34–39 are input-only and can
  never carry I2C. Never `end()` a shared bus: it would deinit the PCA9685.
- **Smooth motion** — use stepped `moveTo`, never instant `write`, to protect linkage and gears.
- **Calibration is per-shutter** — panels differ; never assume one set of µs limits fits all.

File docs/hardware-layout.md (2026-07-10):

# Hardware Layout — hub prototype on solderable copper breadboard

Physical build plan for the hub: what sits on the copper breadboard, what is raised on nylon
standoffs, where the track cuts/bridges go, and which connectors to use. Companion to
[architecture.md](architecture.md) (topology) and [inventory.md](inventory.md) (BOM).

## Assumptions

- **Board:** solderable copper breadboard in the classic 400-point pattern — 30 columns of two
  5-hole strips (`a–e` / `f–j`) with a centre gap, plus a red/blue rail pair top **and** bottom
  (ElectroCookie / SB-400 style). One board builds the whole hub.
- **ESP32:** DevKit on **female pin-socket headers** (its "standoffs") so the module plugs in and
  can be swapped. Column counts below are for the 38-pin DevKitC (19 pins/side); a 30-pin DevKit
  V1 is 15 pins/side — same plan, 4 columns shorter.
- **The breadboard is the chassis.** The XL4015 and PCA9685 bolt **to the breadboard on tall nylon
  standoff pillars** (raised above the ESP32 and rails, overhanging the long edges) so the whole hub
  lifts out as one rigid assembly; the XL4015 overhang also keeps its heatsink in the airflow. The
  **VEML7700 is the exception** — it fixes to the **case lid** so it can see daylight, on a
  detachable J3 lead. The PD trigger also stands on the board, USB-C at the wall cutout.

## The one rule that shapes everything

> **Servo current (2–3 A peak) never touches the breadboard.**
> Breadboard strips are thin copper good for ~0.5–1 A. The 5.1 V *servo* path runs point-to-point
> in 18 AWG: XL4015 OUT → PCA9685 **V+ screw terminal** (bulk cap there). The breadboard carries
> only the ESP32 + logic (~300 mA), fed by its own 5.1 V spur.

---

## Diagram 1 — system overview: on-board vs raised

Hub build overview — raised modules vs breadboard

Common ground is single-point, at the XL4015 OUT− terminal.

---

## Diagram 2 — hub baseboard, plan view

Columns numbered 1–30 left to right. ESP32 USB port faces right (programming access); the
**antenna end overhangs the left board edge** — never sit the antenna over copper.

Hub baseboard plan view

| Ref | Part | Position | Notes |
| --- | ---- | --- | ----- |
| — | 2 × 19-pin female headers | cols 2–20, rows a & j | ESP32 socket. 30-pin DevKit: 15-pin headers, cols 2–16 |
| J1 | 2-pin 5.08 mm screw terminal | cols 28–30, top edge | 5.1 V logic spur in from XL4015 |
| J2 | JST-XH 5-pin | cols 25–27, row f–j side | PCA9685 logic: 3V3 · GND · SDA · SCL · OE |
| J3 | JST-XH 4-pin | cols 28–30, row f–j side | VEML7700 cable: 3V3 · GND · SDA · SCL |
| R1 R2 + C2 | 2 × 100 kΩ + 100 nF | cols 22–24 | optional GPIO34 servo-rail divider (plan D5) |
| C1 | 470 µF + 100 nF | at J1, across 5.1 V/GND rails | local decoupling (bulk cap lives at PCA9685) |

**Wiring the strips under the ESP32:** because a DevKit is wide, its pins land in rows **a** and
**j** and the module covers the rest of each strip. On a *solderable* board that's fine — the
remaining holes (b–e / f–i) of each pin column are your fan-out — but **solder every under-module
jumper and the socket headers before plugging the ESP32 in**, and route the rest on the underside.

Jumpers to fit (short solid-core on top, or bus wire underneath):

| From strip (ESP32 pin) | To |
| --- | -- |
| VIN | top **5.1 V** rail |
| GND (both) | top **GND** rail |
| 3V3 | bottom **3V3** rail |
| GPIO21 (SDA) | J2 pin 3 and J3 pin 3 |
| GPIO22 (SCL) | J2 pin 4 and J3 pin 4 |
| GPIO34 | divider mid-point (only if D5 populated) |
| bottom 3V3 / GND rails | J2 pins 1–2, J3 pins 1–2 |

---

## Diagram 3 — rail plan, cuts and bridges

The two rail pairs get **different voltages** — that's the point of having both:
**top = 5.1 V / GND** (from J1, feeds ESP32 VIN only), **bottom = 3V3 / GND** (from the ESP32
3V3 pin, feeds the I2C devices).

Rail plan — cuts and bridges

Check with the meter **before** soldering:

- **✂ Cut** — if your board ties top and bottom red rails together at either end (some copper
  breadboards do), cut that link: top is 5.1 V, bottom is 3V3.
- **⌒ Bridge** — if the rails are split at the mid-point (many boards copy the solderless break
  at column 15), solder-bridge all four splits — we want full-length rails.
- **No cuts** are needed in the a–e / f–j field: each ESP32 pin owns its column strip.
- Add **one GND tie** between the top and bottom GND rails, near J1.

Running the PCA9685's logic (`VCC`) and the VEML7700 from the **3V3 rail** keeps the I2C bus at
3.3 V — no level shifting, and the VEML7700 is 3.3 V-only anyway. Servo power enters the PCA9685
separately at its V+ screw terminal.

---

## Diagram 4 — raised modules: standoffs and drill plan

Standoff mounting — side elevation

| Module | Holes | Standoff | Fixed to | Notes |
| --- | ----- | --- | --- | ----- |
| Copper breadboard | M3 corner holes (most copper boards have them) | M3 × 10 nylon feet | case floor | the chassis; everything else hangs off it; ESP32 USB reachable |
| PCA9685 | 4 × M2.5 | M2.5 × 15+ nylon pillars | **breadboard** | raised above the rails; servo headers face the loom exit; bulk cap at V+ |
| XL4015 | 2 × M3 | M3 × 15+ nylon pillars | **breadboard** (overhanging edge) | heatsink in open air under the lid vent; ≥ 20 mm clearance |
| AITRIP PD trigger | 2 × M2.5 (varies) | M2.5 × 12 nylon | breadboard edge | USB-C aligned to the wall cutout |
| VEML7700 | 2 × M2 | M2 × 6 nylon | **case lid** | behind the light window; detachable J3 lead + service loop |

**Fixing the modules to the board.** The XL4015 and PCA9685 mounting holes aren't on 0.1" pitch, so
**drill the breadboard** at each hole — in the overhang margin where no wanted strip runs — deburr
both faces, and use **nylon screws + standoffs only** (the strips are live copper; metal hardware
would short adjacent strips). Meter-check that no strip you need was severed by a hole. Tall pillars
(~15–20 mm) let both modules sit above the ESP32 and rails and overhang the long edges; the XL4015
overhang keeps its heatsink in the airflow under the lid vent.

**Light sensor on the lid.** The VEML7700 fixes to the **case lid** (2 × M2 nylon) behind a small
window, so it reads true ambient light instead of sitting behind a board→standoff→lid tolerance
stack-up. Keep it on a **detachable J3 lead with a service loop** so the lid lifts clear of the
board-chassis. Use a **thin clear window** (or an open aperture) — not frosted or tinted; any window
costs a few % of light, so plan a firmware calibration multiplier rather than trusting raw lux
against the 60000 / 30000 solar thresholds.

---

## Diagram 5 — cable loom and connectors

Cable loom — connectors and pinouts

### Connector recommendations (from "the different connectors I can use")

| Connection | Use | Why |
| --- | --- | --- |
| 12 V and 5.1 V power runs | **screw terminals** (on-module) + ferruled 18 AWG | current-rated, re-tightenable, no crimp needed |
| 5.1 V logic spur onto breadboard | **2-pin 5.08 mm screw terminal (J1)** | matches the power-chain style; won't pull out |
| I2C / logic cables (J2, J3) | **JST-XH 2.54 mm** | polarised — can't reverse 3V3/GND; latched, serviceable |
| Servos → PCA9685 | **native 0.1" servo plugs** straight onto CH0–3 | the PCA9685 header *is* a servo header; zero adapters |
| Servo loom → wall (prototype) | grommet holes + strain relief | plan D2 prototype option; revisit JST-XH panel breakout at Phase 7 |
| Anything Dupont | avoid for power; OK for bench probing only | unlatched Dupont on a servo rail is how brownouts happen |

**Don't** run 5 V or servo current through JST-XH shells rated 3 A only at a pinch, and don't use
unpolarised Dupont pairs for anything permanent — one reversed 3V3/GND on the VEML7700 kills it.

### VEML7700 light sensor — its own bus (v0.6.0, [ADR 0011](decisions/0011-dedicated-sensor-i2c-bus.md))

By default the sensor does **not** join the PCA9685 on GPIO21/22. It runs on a second I²C bus,
`Wire1`, so a damaged sensor lead can never wedge the servo driver. Pins are set on the web UI's
**Solar** page — default **SDA GPIO25 / SCL GPIO26**. That page can also switch it to **share** the
PCA9685's bus ([ADR 0012](decisions/0012-selectable-sensor-i2c-bus.md)) — which saves two pins and
is the only option on a single-I²C chip, but gives up the isolation below.

| Do | Why |
| -- | --- |
| **4-pin JST-XH** (3V3 / GND / SDA / SCL) at the sensor end | polarised + serviceable; the sensor sits at the enclosure light window, not next to the PCA9685 |
| Run **SDA / SCL / GND as a twisted trio** | I²C tolerates length poorly because of cable *capacitance*; twisting with ground is the cheap fix |
| Keep the lead **short — ideally < 20 cm** | a second bus buys fault isolation, **not** reach. It does not license a long run |
| **0.1 µF decoupling cap right at the sensor**, own clean 3V3 feed | don't daisy-chain its supply off the servo-side rail — servo inrush is noisy |
| Use normal GPIOs (25/26, or 32/33, 16/17) | **GPIO34–39 are input-only** and physically cannot drive an open-drain I²C line |
| Avoid strapping pins 0 / 2 / 12 / 15 and the servo pin (13) | boot-mode pins misbehave when pulled by a bus |

The VEML7700 breakout carries its own pull-ups, so on a dedicated bus there is nothing to remove
(unlike sharing, where two boards' pull-ups end up in parallel).

---

## Build order

1. Bench-set the **XL4015 to 5.1 V** with a meter, unloaded, before anything else.
2. Breadboard first pass: meter the rails, do the ✂ cut / ⌒ bridge checks from Diagram 3.
3. Solder under-ESP32 jumpers and strip fan-out wires, then the female headers, then J1/J2/J3,
   divider, and decoupling. Continuity-check every net **before** plugging the ESP32 in.
4. Mount modules on standoffs; run the 18 AWG power pairs; fit the bulk cap at PCA9685 V+
   (mind polarity).
5. Power up with **no servos**: check 5.1 V at J1 and PCA9685 V+, 3V3 rail at J2/J3, then
   `i2cdetect`-style scan expects **0x40** (PCA9685) and **0x10** (VEML7700).
6. Add one MG90D on CH0 and re-run the Phase 1 bench test; watch for resets under load.
7. **Fit each servo horn / linkage with the arm parked at HOME (slat closed).** The firmware assumes
   an un-driven channel rests at its minimum-µs "home" endpoint (see
   [decisions/0009-servo-position-memory.md](decisions/0009-servo-position-memory.md)), so assembling
   at HOME means the first move after a factory-fresh boot slews from where the arm actually is instead
   of snapping. (After that, position is remembered across reboots/OTA in NVS.)

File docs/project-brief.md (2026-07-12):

# Project Brief — ESP32 Smart Shutter Hub

**Master engineering specification.** Reusable when restarting the project, briefing another
AI, starting CAD, designing the PCB, or beginning firmware. Written as a design specification,
not a summary.

> **Architecture (locked):** One central **Shutter Hub** (single ESP32) drives a *variable* number
> of **MG90D servo actuator modules** over a short cable loom via a PCA9685 driver. Currently 4
> shutters; expandable or reducible by configuration only. Supersedes the earlier
> "four independent ESP32 shutters" concept.
>
> Decisions of record: [0001 hub vs nodes](decisions/0001-hub-vs-independent-nodes.md) ·
> [0002 servo = MG90D](decisions/0002-servo-mg90d.md) ·
> [0003 power chain + PCA9685](decisions/0003-power-chain-xl4015-pca9685.md) ·
> [0004 custom firmware vs ESPHome](decisions/0004-custom-firmware-vs-esphome.md) ·
> [0005 MQTT command structure](decisions/0005-mqtt-command-structure.md) ·
> [0006 HA via MQTT discovery](decisions/0006-ha-integration-mqtt-vs-custom.md) ·
> [0007 HA Lovelace card](decisions/0007-ha-lovelace-card.md) ·
> [0008 build variants](decisions/0008-build-variants.md) ·
> [0009 servo position memory](decisions/0009-servo-position-memory.md) ·
> [0010 concurrent servo drive](decisions/0010-concurrent-servo-drive.md) ·
> [0011 dedicated sensor I2C bus](decisions/0011-dedicated-sensor-i2c-bus.md) ·
> [0012 selectable sensor I2C bus](decisions/0012-selectable-sensor-i2c-bus.md)

---

## Project Overview

Automate four existing internal plantation shutters in the Front Room, replacing the bulky
commercial **Zemismart JM36/JC601** all-in-one tilt driver with a compact, mains-free (wired 5 V),
smart-home-native system. A single wall-mounted hub tilts the shutter slats via servo-driven
mechanical linkages and provides:

- Apple HomeKit control (each shutter its own accessory)
- Home Assistant integration (one `cover.*` entity per shutter)
- Local web configuration + calibration interface
- OTA firmware updates
- Per-shutter calibration and named favourite positions
- Automatic solar/heat protection from a light sensor
- True multi-shutter synchronisation

Smaller, cheaper, no battery maintenance, and fully local.

---

## 1. Shutter Mechanical Design (the foundation)

The system automates **existing** shutters — it does not lift them, only rotates the slats.

### Installation

| Panel | Location | Servo output (PCA9685) |
| ----- | --- | --- |
| 1 | Front Room Left | CH0 |
| 2 | Front Room Left Centre  | CH1 |
| 3 | Front Room Right Centre | CH2 |
| 4 | Front Room Right | CH3 |

### Panel construction (per panel)

- Width: **~450 mm**
- Slats: **11 per panel**
- Slat height: **~75 mm (3")**
- Material: lightweight wood or PVC blades, plastic tilt linkage
- **Each slat pivots about its centre** (pinned into the frame stiles). **One vertical tilt rod at
  the edge of the frame** links to a point just ahead of each pivot, so lifting/lowering the rod
  rotates all 11 slats together about their centres — the rod moves at one end; the slats turn about
  their middles.

Because the actuator only overcomes slat-rotation friction (not panel weight), the required force
is low — expected **< 1 kg** at the tilt rod. This makes a micro servo entirely adequate.

### Actuation concept

```text
MG90D servo → servo horn → M2 ball-link pushrod → ball joint → shutter tilt rod
```

The servo is mounted **beside/behind the frame edge**, parallel to it, driving the tilt rod through
a pushrod — not coupled directly to the rod (avoids the Zemismart mistake of routing all force
through the gears and demanding perfect alignment).

### Linkage geometry (four-bar, corrected)

> **Correction (2026-07):** the original 10 mm horn : 20 mm arm sizing treated the tilt rod as a
> venetian-blind wand that *twists* (a few mm of pushrod travel). A plantation hidden tilt rod
> **translates without rotating**: every point of it rides a 36 mm arc about its slat's pivot, so
> closed → open moves the rod's bottom pin **~36 mm up and ~36 mm outward** (~51 mm point-to-point).
> The mechanism is a genuine four-bar (servo crank → ball-link coupler → slat-hook rocker).
> Full analysis, collision checks and an interactive simulator:
> **<https://rhamblen.github.io/esp32-shutter-hub/tilt-linkage-design.html>**
> (source: [docs/tilt-linkage-design.html](tilt-linkage-design.html)).

The frame/rail is **28 mm thick (measured)**, which rules out any mortised pocket. The servo
surface-mounts and drives a **slat clip** on the bottom slat (the tilt rod itself sits flush at
closed and cannot be gripped).

**v0.9.2 build baseline (settled):** the owner's Zemismart-style sleeve clip
([cad/slat-hook](../cad/slat-hook)) wedges onto the 8 mm slat (fit confirmed); a drill boss under
the bottom strap, drilled 12 mm from the rear edge, carries the M2 ball pin at **26.6 mm @ −16°**.
The MG90D cradle **tapes** to the rail's rear face (case bonded in, no screws, tabs unused), axis
**(+24.7, −49)**, stock 20 mm horn, **M2×35 pushrod at 58 mm**. ~132° sweep → 90° slat travel,
jam margin 9.3 mm, torque ratio ≤0.77 (≈2.9 kg·cm at slats), rear-most 44.7 mm — everything hidden,
slats close rear-edge-up. Cradle drawings:
[diagrams/servo-cradle-p1.svg](diagrams/servo-cradle-p1.svg) and design doc §7.

**v0.9.1 (front-edge hook variant, retained as a preset):** pin 24 mm on the front-edge
line (06:00 closed → 03:00 room-side open), stock 20 mm horn, **M2×25 pushrod at
46 mm**, servo axis **(+32, −30)**. ~114° sweep, jam margin 11.3 mm, ratio ≤0.85. Drawing:
[diagrams/linkage-geometry-front-edge.svg](diagrams/linkage-geometry-front-edge.svg).

The v0.9.0 layouts below remain valid only if the hook's pin can sit near the rear edge (longer
under-slat strap); each works with one closure direction only:

| Element | **A — rear mount (recommended, hidden)**  | B — front mount (visible) |
| --- | --- | --- |
| Closure direction | rear slat edge UP at closed | rear slat edge DOWN |
| Slat-hook crank pin | 26 mm radius, phase −10° | 26 mm radius, phase −170° |
| Servo arm | stock **20 mm** horn | stock **20 mm** horn |
| Pushrod hole-to-hole| **58 mm** → M2×40 (58–68) or M2×35 | **52 mm** → M2×30 (48–58) |
| Servo axis (x, y) | (+23, −47) = ½ frame + ½ servo + 3 mm plate| (−21, −41) |
| Servo sweep | ~122° of 180° → 90° slat travel | ~123° |
| Torque (worst case) | ≤0.84× → ≈2.6 kg·cm at slats | ≤0.86× → ≈2.6 kg·cm |
| Depth used | ≤43 mm — within the rod's own sweep | ~27 mm proud into the room  |

Jam margin is ≥10 mm of effective horn arm throughout both layouts (no dead-centre). The slat hook
must sit **≥10 mm inboard of the tilt rod's plane** so the rod passes beside the pushrod (they cross
in x–y but live in different vertical planes). Servo shaft points inboard; a flipped/mirrored servo
only reverses rotation, which the per-shutter µs endpoint calibration absorbs — no firmware change.

### Linkage parts (chosen)

- **M2 ball-link pushrod** — rear mount wants **58 mm hole-to-hole** (M2×40, range 58–68, or M2×35
  at full extension); front mount wants **52 mm** (M2×30, range 48–58). The owned M2×50s (68–78 mm)
  are too long uncut; keep as spares. 304 stainless rod + nylon ball ends; threaded ends give
  ±5 mm adjustment and low backlash.

---

## 2. Servo (locked): MG90D

**MG90D digital metal-gear micro servo** — chosen over MG90S/analogue for digital control accuracy
and repeatability, and hugely over-margined vs. a DS3235-class servo (unnecessary here).

| Spec | Approx value |
| --- | --- |
| Type | Digital micro servo |
| Gears | Metal |
| Voltage | 4.8–6 V |
| Size | ~23 × 12 × 29 mm |
| Weight | ~13–14 g |
| Torque | ~2 kg·cm class |
| Control | PWM (via PCA9685) |

Torque check: ~1 kg force at a ~15–20 mm arm ≈ 15–20 kg·mm required vs. ~200 kg·mm available →
large safety margin. Final horn/arm ratio confirmed after the bench force test (see plan Phase 0).

---

## 3. System Architecture

```text
                    iPhone / Siri            Home Assistant
                         |                        |
                    Apple Home                 MQTT / API
                         | HomeKit                |
                         +-----------+------------+
                                     |
                            +------------------+
                            |   SHUTTER HUB     |  ESP32-D
                            |  Web UI · OTA     |  HomeSpan bridge (N accessories)
                            |  VEML7700 (I2C)   |  MQTT discovery
                            +--------+---------+
                                     | I2C (GPIO21/22)
                                +----------+
                                | PCA9685  |  16-ch servo driver
                                +----+-----+
             CH0        CH1        CH2        CH3   ... (variable)
              |          |          |          |
           MG90D      MG90D      MG90D      MG90D
           Left    Left Centre Right Ctr    Right
              |          |          |          |
          tilt rod   tilt rod   tilt rod   tilt rod
```

The hub is the single point of integration, configuration, OTA, and light sensing. Actuator
modules are mechanical-only (MG90D + horn + pushrod + printed bracket). Servo count is driven by a
config array, so any number of shutters (1 or more) works with the same firmware.

---

## 4. Power System (locked, ordered)

```text
USB-C PD charger (30W+)
      │
AITRIP PD trigger board  →  12 V
      │
XL4015 buck converter    →  set to 5.1 V   (≈5 A rated; replaces LM2596)
      │
      ├─ ESP32-D (VIN)          ~0.25 A
      ├─ PCA9685 (V+)           ~0.05 A
      └─ Servo rail ──┬── MG90D ×4   2–3 A peak (all moving)
                      │
                  1000–2200 µF electrolytic (≥10 V) near PCA9685
      Common ground throughout (single point)
```

- **XL4015 chosen over LM2596** for headroom: the LM2596 is realistically ~1.5–2 A (3 A marginal,
  heat-derated) — too close to the ~2–3 A servo peak. XL4015 gives ~1 A+ margin. Set output to
  **5.1 V** *before* connecting anything. (A spare LM2596 exists but is superseded.)
- Servos powered from the buck rail directly, **not** through the ESP32 board.
- Bulk capacitor on the servo rail is mandatory insurance against MG90D inrush dips.
- Enclosure must **vent above the XL4015** — it warms when all servos move together.

### Hub pinout (ESP32-D)

Defaults; all of them are runtime-configurable and persisted in NVS. Full table — including the
ESP32-C3 proposal and the pins the firmware refuses — in [pinout.md](pinout.md).

| Pin | Function |
| --- | --- |
| GPIO21 (SDA)  | I2C `Wire` — **servo bus**, PCA9685 (0x40) |
| GPIO22 (SCL)  | I2C `Wire` clock |
| GPIO25 (SDA)  | I2C `Wire1` — **sensor bus**, VEML7700 (0x10) |
| GPIO26 (SCL)  | I2C `Wire1` clock |
| GPIO13 | Servo signal — `-direct` builds only |
| GPIO34 | (optional) servo-rail voltage monitor (ADC, brownout detect) |
| GPIO0 | Boot / recovery |
| PCA9685 CH0–3 | Servo PWM → shutters 1–4 |

The I2C addresses do not conflict, so the PCA9685 and VEML7700 *could* share one bus — but from
v0.6.0 they deliberately do not. The sensor runs on its own `Wire1`, so a fault on its long lead to
the window can never wedge the servo bus and strand the shutters. See
[ADR 0011](decisions/0011-dedicated-sensor-i2c-bus.md).

---

## 5. Light Sensor & Solar Protection

**VEML7700** ambient light sensor (I2C, 0–120,000 lux) at the hub. Purpose is **strong direct
sunlight detection for summer heat protection**, not general room lighting.

```
Trip:  lux > 60000 for 10 min  → move affected shutters to Privacy
Clear: lux < 30000 for 20 min  → return to Daylight
```

Thresholds/timers configurable. One sensor at the hub serves the whole room.

---

## 6. Calibration & Favourite Positions

Every panel differs slightly, so the hub stores **per-shutter** limits and named positions as
servo pulse widths (µs):

| Position | Meaning | Example |
| --- | --- | --- |
| `closed` | Slats closed, no gap | 1620 µs |
| `privacy`  | Light, limited view  | 1750 µs |
| `daylight` | Normal daytime | 1850 µs |
| `open` | Max light/airflow | 2190 µs |

Position % maps linearly between `closed` and `open`:
`pwm = closed + (open − closed) × (pos% / 100)` (e.g. 50 % of 1620–2190 → 1905 µs).

### Calibration web UI (per shutter)

```
Front Room Left        Current: 1850 µs
Jog: [-100][-10][-1][+1][+10][+100]
[SET CLOSED] [SET OPEN]
Favourites: [SET DAYLIGHT] [SET PRIVACY]
[SAVE]
```

---

## 7. Configuration Model

One JSON document on the hub describes the whole system; shutter count is data, not code:

```json
{
  "hostname": "shutter-hub",
  "mqtt": { "enabled": true, "host": "...", "topic_prefix": "shutterhub" },
  "solar": { "trip_lux": 60000, "trip_minutes": 10, "clear_lux": 30000, "clear_minutes": 20 },
  "shutters": [
    { "id": 1, "name": "Front Room Left",         "channel": 0, "invert": false,
      "cal": { "closed": 1620, "privacy": 1750, "daylight": 1850, "open": 2190 } },
    { "id": 2, "name": "Front Room Left Centre",  "channel": 1, "invert": false, "cal": {} },
    { "id": 3, "name": "Front Room Right Centre", "channel": 2, "invert": false, "cal": {} },
    { "id": 4, "name": "Front Room Right",        "channel": 3, "invert": false, "cal": {} }
  ]
}
```

Stored in LittleFS (JSON, web files) + Preferences (small calibration values). A single-shutter
install is just a one-element array.

---

## 8. Firmware Architecture (appliance-style, custom)

Not a flat Arduino sketch — structured like small appliance firmware. **Custom firmware
(HomeSpan + MQTT), not ESPHome** — chosen so we keep native HomeKit, custom smooth servo motion,
the calibration web UI, and full OTA control (see [ADR 0004](decisions/0004-custom-firmware-vs-esphome.md)).
Structural reference: [HomeKey-ESP32](https://github.com/rednblkx/HomeKey-ESP32) — a proven
HomeSpan + web-config + web-OTA design (we stay on Arduino Core rather than its ESP-IDF/Svelte stack).

- **Core:** Arduino Core for ESP32.
- **WiFi:** WiFiManager — first-boot AP + captive portal (`Shutter-Hub-Setup`), stores credentials.
- **Web:** ESPAsyncWebServer + AsyncTCP; HTML/CSS/JS in LittleFS. Single multi-shutter page +
  per-shutter calibration + OTA page.
- **HomeKit:** HomeSpan configured as a **bridge**, one `Window Covering` accessory per shutter.
- **HA:** MQTT discovery, one cover + sensors per shutter.
- **OTA:** custom browser uploader (core `Update.h`) — firmware and/or the LittleFS image, with an
  installed-version display and upload log. (ElegantOTA served the v0.0.x scaffold and was replaced.)
  Optional auto-update checking a `latest.json` remains deferred (plan D3).
- **Config:** **all settings in NVS (Preferences)**; LittleFS holds only the web assets, so a
  filesystem OTA never touches a setting (ADR 0005).
- **Servo:** `ServoController` class exposing `moveTo(percent)` with soft-start / slow, stepped
  movement (not instant `write`), staggered start-up across channels to limit inrush.
- **Discovery:** mDNS → `shutter-hub.local`.

```
ShutterHub/
  src/  main.cpp  WiFiSetup.cpp  WebServer.cpp  Ota.cpp
        ServoController.cpp  HomeKit.cpp  Mqtt.cpp  LightSensor.cpp
        Config.cpp  Diagnostics.cpp
  data/ index.html  style.css  app.js
```

Firmware iterates the `shutters[]` array — generic over shutter count.

---

## 9. Web Interface

Single page at `http://shutter-hub.local`:

- **Status** — WiFi, per-shutter position, firmware version, live lux.
- **Control** — per shutter OPEN/CLOSE/STOP + 0–100 % slider; group **Open All / Close All /
  Daylight**.
- **Calibration** — per-shutter servo setup (§6).
- **OTA** — firmware upload.

```
Front Room Shutters
  Left          [====50%====] [Open][Close][Stop]
  Left Centre   [====50%====] [Open][Close][Stop]
  Right Centre  [====50%====] [Open][Close][Stop]
  Right         [====50%====] [Open][Close][Stop]
[Open All] [Close All] [Daylight]
```

---

## 10. Home Assistant Integration

MQTT discovery publishes per shutter:

```
cover.front_room_left / _left_centre / _right_centre / _right
sensor.shutter_hub_lux
sensor.front_room_left_position (etc.)
```

Commands: Open / Close / Stop / Set position / go-to favourite.

### Example automations
- **Morning** — sunrise + 20 min → Daylight.
- **Strong sun** — lux > 60000 AND temperature high → Privacy.
- **Evening** — sunset → Close.

---

## 11. Manual Override

Automation must not fight the user. On any manual move (web/HomeKit/HA), **suspend automation for
that shutter for 2 hours**, then resume. Tracked per shutter.

---

## 12. Safety Features

- **Watchdog** — recover from hangs.
- **Servo movement timeout** — max ~15 s of drive per move; stop + flag error if exceeded.
- **Movement limits** — hard min/max PWM per shutter; never drive past calibrated `closed`/`open`.
- **Brownout / staggered start-up** — ESP32 on isolated rail; stagger servo motion to limit inrush.

---

## 13. Enclosures

### Hub box (wall-mounted)
Compartments: USB-C entry → AITRIP trigger → XL4015 (**vent slots above**) → ESP32-D + PCA9685 →
servo cable exits ×N. **VEML7700 light window** on the face. Servo outputs 3-wire (+5 V / GND /
PWM); connectors either grommet holes + strain relief (prototype) or JST-XH (tidier) — see open
decisions.

```
+------------------------------------+
| USB-C                              |
| [AITRIP trigger]                   |
| [XL4015]   <-- ventilation slots   |
| [ESP32-D]  [PCA9685]               |
| Servo outputs:  o   o   o   o      |
|                S1  S2  S3  S4      |
| Light-sensor window (VEML7700)     |
+------------------------------------+
```

### Actuator module (per shutter, printed)
MG90D + multi-hole horn + M2×50 pushrod + multi-hole shutter clamp arm, mounted at the frame edge,
target footprint roughly **30 × 20 × 15 mm** of visible mechanism, hidden behind side trim where
possible.

---

## 14. Future Expansion

- **I2C header** reserved (3V3 / GND / SDA / SCL) for extra sensors, current monitor, OLED.
- **Independent single-servo nodes** for *other rooms* later — an ESP32-C3 driving one servo straight
  off a GPIO (the `esp32c3-direct` variant), running this same firmware with a one-entry `shutters[]`
  array. There is **no hub-to-node protocol**: each node is an independent MQTT peer and HomeSpan
  bridge, and cross-room coordination is a Home Assistant automation or `cover` group. Deferred; see
  [ADR 0001](decisions/0001-hub-vs-independent-nodes.md).

---

## Final Product Definition

**ESP32 Smart Shutter Hub** — a modular controller driving a configurable number of MG90D
servo-operated shutter tilt mechanisms.

✅ Single ESP32 hub · N servo outputs (initially 4) via PCA9685 ·
✅ MG90D + M2 ball-link tilt actuation · ✅ per-shutter calibration + named favourites ·
✅ Apple HomeKit (HomeSpan bridge) · ✅ HA MQTT covers + sensors · ✅ single local web UI + OTA ·
✅ VEML7700 solar heat protection · ✅ manual-override handling · ✅ expandable to more shutters/rooms.

See [project-plan.md](project-plan.md) for the phased build roadmap and
[inventory.md](inventory.md) for the bill of materials.

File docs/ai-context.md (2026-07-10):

# AI Context — cold-start orientation

Dense factual map for the next AI session. Not for end users. Read this first.

## Purpose

Automate 4 existing Front Room plantation shutters (tilt-only) with one **ESP32 Shutter Hub**
driving a **variable** number of **MG90D** servo actuators via a **PCA9685**, integrated with
**Apple HomeKit (HomeSpan)** and **Home Assistant (MQTT)**. Replaces a Zemismart JM36/JC601.

## How to work here

- The **repo is the source of truth for intent + rationale.** Update docs when decisions change.
- Architecture and part choices are **locked via ADRs** in `docs/decisions/` — don't silently
  re-open them; if reversing, write a new ADR.
- Shutter count is **configuration, not code** — never hard-code "4".
- Follow the user's phased-repo doc conventions (status table, ADRs, CHANGELOG per phase).

## File map

| File | Contents |
| ---- | --- |
| `README.md` | Shop-window overview |
| `docs/project-brief.md` | Master engineering spec (mechanical + electronics + firmware) |
| `docs/project-plan.md` | Phased roadmap + status table + open decisions |
| `docs/architecture.md` | Principles, trade-off table, topology, gotchas |
| `docs/inventory.md` | Shutter facts + BOM + power budget |
| `docs/hardware-layout.md` | Copper-breadboard build plan: placement, cuts, standoffs, cables, connectors |
| `docs/installation.md` | End-user install guide: flash → WiFi → calibrate → HA → HomeKit → solar |
| `docs/user-guide.md` | Everyday operation, solar behaviour, recalibration, troubleshooting |
| `docs/pinout.md` | GPIO map: ESP32-D defaults, C3 proposal, pins `validGpio()` rejects |
| `docs/ha-lovelace-card.md` | Lovelace card spec: entity model, config schema, layout |
| `docs/decisions/0001–0012` | ADRs: hub, MG90D, XL4015+PCA9685, custom firmware, MQTT commands, MQTT-only HA, Lovelace card, build variants, position memory, concurrent drive, dedicated sensor I2C bus, selectable sensor bus |
| `firmware/data/` | LittleFS web UI (index.html, style.css, app.js, qrcode.min.js) served by `WebUI` |
| `ha-card/shutter-hub-card.js` | The shipped Lovelace card (plain custom element, no build step) |
| `CHANGELOG.md` | Keep-a-Changelog; update every phase |
| `RELEASE_NOTES.md` | Body of the **current** GitHub release (rewritten each release) |

## Locked facts

- **Shutters:** 4 panels, ~450 mm wide, 11 slats, ~75 mm slat height, edge tilt rod, lightweight.
  Count is configuration, but `Shutters::MAX` (`firmware/include/Shutters.h`) currently caps it at
  **4** — iterate the array, never hard-code 4, and raise `MAX` if more are needed (Phase 8 wants 6).
- **Servo:** MG90D (digital metal gear, ~2 kg·cm, ~13–14 g, 4.8–6 V).
- **Driver:** PCA9685 (I2C 0x40, CH0–3).
- **Sensor:** VEML7700 (I2C 0x10). Its bus is a **setting** ([ADR 0012](decisions/0012-selectable-sensor-i2c-bus.md)):
  **dedicated `Wire1`** (default, SDA 25 / SCL 26, fault-isolated per [ADR 0011](decisions/0011-dedicated-sensor-i2c-bus.md))
  or **shared** with the PCA9685 on `Wire` (21/22). Dedicated needs `SOC_I2C_NUM > 1` — true on the
  ESP32-D, **false on the C3**, where the preference is clamped to shared.
- **Power:** USB-C PD → AITRIP trigger (12 V) → XL4015 @ **5.1 V** → ESP32 + PCA9685 + servo rail;
  1000–2200 µF bulk cap; common ground. XL4015 replaced LM2596.
- **Linkage:** M2×50 mm ball-link pushrod (hole-to-hole 68–78 mm); horns 8/10/12 mm; printed arm
  holes 15/20/25 mm; start 10 mm horn + 20 mm arm. **Under bench validation (project-plan D1):** rod
  end appears to need ~36 mm rise + ~36 mm out over 0→90° → effective crank radius ~36 mm, not 20 mm.
- **Pinout:** GPIO21 SDA + GPIO22 SCL (`Wire`, PCA9685); GPIO25 SDA + GPIO26 SCL (`Wire1`,
  VEML7700, configurable); GPIO34 optional servo-rail ADC, GPIO0 boot. GPIO34–39 are input-only —
  they can never carry I2C.
- **Firmware:** custom Arduino (not ESPHome); HomeSpan bridge + MQTT (PubSubClient); ESPAsyncWebServer
  + LittleFS SPA + `/ws/logs` WebSocket; WiFiManager; custom OTA (firmware + LittleFS);
  `ServoController.moveTo()` smooth/staggered.
- **MQTT/HA (ADR 0005, implemented v0.4.0):** browser-owned config; servos declared manually (no PWM
  auto-scan); each shutter = one HA `cover` (position 0–100 = slat angle) on `<base>/cover/<id>/…` +
  six `button`s (jog_open/jog_close on `cmd`, `recall:`/`save:` `daylight`/`privacy`); state topics
  `position` + `state` retained; hub-wide LWT `<base>/status`. Jog = 25 µs/press, clamped to
  calibration. Uncalibrated ⇒ reports 0/closed, OPEN/CLOSE/position ignored (logged). Discovery
  re-publishes on shutter config change. Phase-8 calibration cmds (`goto_us`, `save:open/close`) deferred.
  Config in NVS, web assets in LittleFS.
- **Servo drive (ADR 0010, v0.4.0):** per-slot slew state — all channels move concurrently at the
  shared speed; bench API acts on the active test channel; slot API (`moveSlotUs` …) for MQTT.
- **Solar (ADR 0011 + 0012, v0.6.0/v0.6.1):** `LightSensor` (VEML7700 on the selected bus, lean vendored driver, fixed
  gain 1/8 + IT 25 ms → ~1.8432 lx/ct, full scale ≈120 k lx, **linear lux — no Vishay correction**,
  so reported lux is approximate) + `SolarLogic` (`idle→counting-trip→tripped→counting-clear`).
  Defaults: trip >60000 lx for 10 min → **Privacy**; clear <30000 lx for 20 min → **Do nothing**.
  Both targets are one of **open|closed|daylight|privacy|none** (`AppConfig::SolarTarget`, 0–4);
  `none` advances state but drives nothing. Solar config applies **without a reboot**.
  Web: **Solar** page + `/api/solar`, `/api/solar/simulate` (simulate-lux slider works with no
  sensor fitted). MQTT: `<base>/solar/{lux,brightness,state}` published retained; `<base>/solar/{enable,
  trip_lux,clear_lux}/set` subscribed → HA illuminance + brightness-% + state sensors, an automation
  switch and two writable `number` thresholds (clear ≥ trip is rejected). Card keys:
  `solar_switch`/`solar_lux`/`solar_state`, all optional.
- **`brightness` is display-only** (`LightSensor::brightnessPct()`): `20 × log10(clamp(lux,1,1e5))`,
  one lux decade per 20 points — 0 dark … 100 full sun. Perceptual, not linear (a linear % of the
  120 k full scale reads 0 % indoors). It **compresses the 30–60 k trip band to 90 %–96 %**, so the
  state machine trips on raw lux and never on this. Raw `lux` also stays as the Phase-8b history source.
- **Info page hardware table (v0.6.2):** `GET /api/info` carries `servo` (`usesPca,pin,channel,sda,
  scl,attached`), `sensor` (`enabled,present,bus,sda,scl,dedicatedSupported` — pins are the **active**
  ones, post-clamp), `homekit` (`enabled,running,paired,controllers`) and `shutters`
  (`name,channel,calibrated`). `renderHw()` in `data/app.js` draws one row per physical device; it is a
  **read-only mirror** — pins are set on Servo test, channels on Shutters, the sensor bus on Solar.
  On a PCA9685 build `ServoController::pin()` aliases the channel, so the UI branches on `usesPca`.
- **Manual override:** a web recall or an MQTT set/position/jog/recall calls
  `SolarLogic::notifyManualMove(id)` → automation suspended **2 h on that shutter** (ephemeral, not
  persisted). SolarLogic's own moves go straight to `ServoController::moveSlotUs` and never self-suspend.

## Build phases

Done: **S** (v0.0.1–3 framework + WiFi + OTA), **1** (v0.1.0 single-servo bench test; v0.2.1 adds a
persisted **speed slider** 5–120 °/s default 25, `POST /api/servo/speed?dps=N`, slewed moves),
**S2** (v0.2.0 LittleFS web UI + WebSocket logs + MQTT/HA config), **2** (v0.2.2–v0.3.0 Shutters
page + calibration; PCA9685 backend + build variants + position memory). Phase 3 retired (folded
into S/S2), **4** (v0.4.0 MQTT/HA covers + buttons + discovery + concurrent drive; verified on
hardware), **4b** (v0.4.2 Lovelace operating card). **5 HomeKit** ✓ **works** (v0.5.0–v0.7.2):
HomeSpan bridge (`firmware/src/HomeKit.cpp`), one Window Covering accessory per shutter driving the
same `ServoController` slots as MQTT; config tab (`/api/homekit`, NVS `hk*` keys, default setup code
**748-88-377**, client-side `X-HM://` QR). Discovers, pairs, and syncs both ways (Home ↔ HA).
**Root cause of the long "never pairable" saga (fixed v0.7.0):** HomeSpan 1.9.1's hostname self-check
uses `sscanf(hostName,"%m…")`, and **newlib-nano doesn't implement `%m`**, so the bridge hit
`while(1) PROGRAM HALTED` before advertising `_hap._tcp` / opening 1201 — *not* mDNS, WiFi, or cores
(all chased as red herrings). Fixed by a **vendored HomeSpan patch** (`firmware/patches/HomeSpan.cpp`
+ `patches/apply_patches.py`, `extra_scripts`) — do NOT drop it. **Pinned `HomeSpan @ ~1.9.1`** — last
line supporting arduino-esp32 **core 2.0.9** (2.x needs core ≥3.3.0; do NOT bump the core, it would
churn every other lib). Coexistence (all in HomeKit.cpp): HAP `setPortNum(1201)` (web keeps 80); **mDNS
is initialised by `WebUI::begin()` on the main thread** (hostname + `_http._tcp`) and HomeSpan just
ADDS `_hap._tcp`; WiFi stays with WiFiManager (HomeSpan sees `WL_CONNECTED`, never calls WiFi.begin);
`setQRID("SHUT")` + `setPairingCode(code,false)`; `autoPoll` on core 1; a WARN watchdog flags a stalled
bridge. **Gotcha: the pairing verifier is baked at boot** — a code/enable/name change needs a reboot
(the tab has *Reboot to apply*; the active code is logged to the web Logs page). `paired()` reads the
persisted controller list, so status is correct after reboot/OTA (v0.7.2). Uncalibrated shutters still
operate via the servo envelope (MVP). **6 light/solar** ✓ built
(v0.6.0–v0.6.2): `LightSensor` + `SolarLogic` + Solar page + MQTT solar entities + card header toggle
(v0.6.0); selectable sensor bus (v0.6.1, [ADR 0012](decisions/0012-selectable-sensor-i2c-bus.md));
Info-page hardware table + brightness-% sensor (v0.6.2) — see the Solar locked fact above and
[ADR 0011](decisions/0011-dedicated-sensor-i2c-bus.md).
**Flash ~91.6 %** of the app partition (`esp32d-pca9685`; 92.2 % `esp32d-direct`, C3 envs link at
~89.8 % / 90.4 %) — treat any new library as suspect; that's why the
VEML7700 driver is hand-rolled rather than Adafruit's. Remaining: **7** production → **8** HA
calibration card (optional) → **8b** HA-side threshold calibration from lux history (optional).
**0** (mechanical force test) still open. The solar path is exercised end-to-end through the
simulate-lux slider; **v1.0.0 is gated on the Phase 7 physical build-out** (enclosures, PCB, all four
shutters mounted), not on any feature work.

## Gotchas

- Set XL4015 to 5.1 V before wiring anything.
- Stagger servo start-up; keep bulk cap; ESP32 on the rail, not through the board; vent the XL4015.
- Stepped `moveTo`, never instant `write`.
- Calibration is per-shutter — panels differ.
- **I2C: two buses by default.** PCA9685 0x40 on `Wire` (21/22); VEML7700 0x10 on `Wire1` (25/26).
  They *could* share one bus (distinct addresses); ADR 0011 chose not to so a sensor-lead fault
  can't wedge the servo driver. ADR 0012 made it a **setting** — don't hard-code either way.
- **Never `end()` the shared bus.** `LightSensor::reconfigure()` only ever calls `Wire1.end()`
  (guarded by `g_dedUp`). `Wire.end()` would deinit the PCA9685 and freeze every servo.
  `TwoWire::begin()` *is* idempotent on a started master bus, so shared mode needs no handshake.
- `Wire.begin()` only runs inside `#if USE_PCA9685` in ServoController — on a `-direct` build in
  shared mode, `LightSensor` is the first caller and brings `Wire` up itself.
- **`SOC_I2C_NUM` is 2 on the ESP32-D, 1 on the C3**, but the Arduino core declares `Wire1`
  unconditionally — so a C3 build *links* and fails silently at runtime. Capability must be gated
  on `SOC_I2C_NUM`, never on "it compiled".
- The **LittleFS image is shared across all variants**, so any per-chip/per-variant UI difference
  must come from the API at runtime (`usesPca`, `dedicatedSupported`), never from build-time markup.

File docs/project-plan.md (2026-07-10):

# Project Plan — ESP32 Smart Shutter Hub

Phased roadmap. Phases map loosely to minor versions (Phase 1 → v0.1.0). See
[project-brief.md](project-brief.md) for the full spec and [inventory.md](inventory.md) for parts.

## Status

☐ not started · ◐ in progress · ☑ done

| Phase | Version | Title | Status |
| ----- | --- | --- | --- |
| 0 | — | Mechanical proving / force test| ☐ |
| S | v0.0.1–3| Firmware framework + OTA scaffold | ☑ |
| 1 | v0.1.0  | Bench bring-up (1 servo) | ☑ |
| S2 | v0.2.0  | Web UI shell (LittleFS SPA) + Logs (WS) + MQTT/HA config | ☑ |
| 2 | v0.2.x–v0.3.0 | Shutters config + calibration; PCA9685 backend + build variants | ☑ |
| 4 | v0.4.0  | MQTT / Home Assistant covers | ☑ |
| 4b | v0.4.x  | HA Lovelace operating card | ☑ |
| 5 | v0.5.0–v0.7.2 | HomeKit (HomeSpan bridge) | ☑ pairing works |
| 6 | v0.6.0–2| Light sensor + solar logic | ☑ |
| 7 | v1.0.0  | Enclosures, PCB, all 4 shutters, diagnostics | ☐ |
| 8 | — | HA calibration card (optional) | ☐ |
| 8b | — | HA-side threshold calibration from lux history (optional) | ☐ |

**Sequence note (post-v0.1.0):** the polished web UI, live logs, and MQTT/HA *config* were pulled
forward — they all run on a bare ESP32 before servo hardware exists. So the old "Phase 2 Web UI" and
"Phase 3 WiFiManager/OTA" are effectively **done** (Phase S + S2); Phase 3 is retired (WiFi
provisioning now lives in the System > WiFi sub-tab). Per-shutter **calibration** (Phase 2) is now
**done** on real PCA9685 hardware (v0.3.0), and MQTT **cover control** (Phase 4) was verified on
hardware on 2026-07-09. **HomeKit pairing** (Phase 5) works as of v0.7.0 — the fix was HomeSpan 1.9.1's
`sscanf("%m…")` hostname check, which newlib-nano doesn't implement — and the **light sensor + solar
logic** (Phase 6) is in place. What remains for **v1.0.0** is the physical build-out (Phase 7):
enclosures, PCB, all four shutters mounted behind the wall, and end-to-end diagnostics.

**Build variants (v0.3.0):** the servo backend is now a compile-time choice — **direct GPIO** (one
bench actuator) or **PCA9685** (I2C multi-channel) — with a `FW_VARIANT` id surfaced on the
info/OTA screens and in the artifact names. Four envs (`esp32d-` / `esp32c3-` × `-direct` /
`-pca9685`); only the ESP32-D pair is active, `esp32d-pca9685` is the default. See
[decisions/0008-build-variants.md](decisions/0008-build-variants.md). Servo positions are remembered
across reboots/OTA (NVS) with an assembly "home" default, so the first move slews rather than snaps
([decisions/0009-servo-position-memory.md](decisions/0009-servo-position-memory.md)). From **v0.4.0**
servo drive is **concurrent per channel** — every commanded output slews independently, so an HA
"close all" moves all shutters at once ([decisions/0010-concurrent-servo-drive.md](decisions/0010-concurrent-servo-drive.md)).

**OTA-first reordering:** the web-server stack **and** WiFiManager captive-portal provisioning
(originally Phase 3) were pulled forward as **Phase S** (`v0.0.1`) so every later phase flashes over
WiFi, no credentials in the binary. **Phase S2** (`v0.2.0`) then moved the UI into a LittleFS
single-page app (sidebar shell, WebSocket logs, MQTT/HA discovery config) — see
[decisions/0005-mqtt-command-structure.md](decisions/0005-mqtt-command-structure.md).

---

## Phase S — Firmware framework + OTA scaffold (v0.0.1) ☑
- **Objective:** a buildable base image with on-device WiFi setup + browser control + OTA, before
  any servo work.
- **What we built:** PlatformIO project (`esp32dev` + `esp32-c3-devkitm-1`, Arduino Core);
  WiFiManager AP `Shutter-Hub-Setup` + captive portal storing creds in NVS (survives OTA); mDNS
  `shutter-hub.local`; ESPAsyncWebServer status page with a "Change WiFi" control; ElegantOTA at
  `/update`. Per board: an OTA `firmware.bin` + a merged full-flash image for the one-time USB flash.
- **Exit criteria:** ☑ compiles; set WiFi on-device, then update over the air from the browser.

---

## Phase 0 — Mechanical proving / force test
- **Objective:** confirm the MG90D + M2×50 linkage actually swings a real tilt rod, and fix the
  horn/arm ratio.
- **What we build:** a printed servo test bracket + multi-hole shutter arm; temporary mount on one
  panel.
- **Prerequisites:** MG90D, M2×50 pushrod, horns, a luggage/fishing scale.
- **Do:** measure tilt-rod force through full travel (pull with the scale). `<500 g` → tiny servo
  fine; `500 g–1 kg` → MG90D ideal; `>1 kg` → longer arm / better linkage. Measure closed→open
  rod travel. Choose horn (8/10/12) + arm hole (15/20/25).
- **Exit criteria:** one shutter fully closes and fully opens from servo motion alone, repeatably.

## Phase 1 — Bench bring-up (v0.1.0)
- **Objective:** ESP32-D + PCA9685 + one MG90D moving under serial control.
- **What we build:** breadboard rig on the XL4015 rail (5.1 V) + bulk cap; `ServoController` skeleton.
- **Prerequisites:** Phase 0 geometry; XL4015 set to 5.1 V; PCA9685 wired on I2C (GPIO21/22).
- **Do:** serial commands `open` / `close` / `50`; verify smooth stepped `moveTo`, no ESP32 resets
  under servo load.
- **Exit criteria:** repeatable position control of one servo, stable power.

## Phase S2 — Web UI shell + Logs + MQTT/HA config (v0.2.0) ☑
- **Objective:** a maintainable, polished device UI + observability + MQTT groundwork, all runnable
  on a bare ESP32 before servo hardware.
- **What we built:** LittleFS single-page app (`data/{index.html,style.css,app.js}`, sidebar shell
  modelled on HomeKey-ESP32) served over a JSON/REST API; **live log stream** over `/ws/logs`
  (ring buffer + level filters); **MQTT** broker config + **Home Assistant discovery** for hub
  diagnostic sensors (`PubSubClient`, config in NVS); **System** page with quick actions, WiFi
  sub-tab, and web-auth. Embedded recovery page if the FS image is missing.
- **Exit criteria:** ☑ compiles; UI served from LittleFS; logs stream live; MQTT connects and the
  hub appears in Home Assistant.

## Phase 2 — Shutters config + calibration; PCA9685 backend + build variants (v0.2.x–v0.3.0) ☑
- **Objective:** define shutters and calibrate each per-panel, in the browser, persisted — on real
  PCA9685 hardware.
- **What we built:** a **Shutters** config surface (count, friendly names, PCA9685 channels — manual,
  no auto-scan; see ADR 0005) + jog / SET CLOSED / SET OPEN / **Daylight**/**Privacy** favourites,
  stored in NVS so a filesystem OTA doesn't wipe calibration — a **separate page** from the low-level
  **Servo test** bench diagnostic (the old Actions tab). Then (v0.3.0) the **PCA9685 servo backend**
  went live as a **build variant** (`USE_PCA9685`, [ADR 0008](decisions/0008-build-variants.md)) with
  a runtime-adaptive Servo-test page (I2C-pin + channel selectors); selecting a shutter routes drive
  to its channel, channel-switching causes no motion, and **servo positions persist in NVS**
  ([ADR 0009](decisions/0009-servo-position-memory.md)) so the first move slews from where the arm is.
- **UI mockup:** [diagrams/calibration-page.svg](diagrams/calibration-page.svg) — dark-theme wireframe
  of the Shutters page: shutter selector, µs scrubber, transport cluster (slow-run → stop → nudge),
  endpoint SET buttons, and Daylight/Privacy favourites.
- **Prerequisites:** Phase 1 servo control; PCA9685 on I2C.
- **Exit criteria:** ☑ calibrate closed/open + Daylight/Privacy per shutter in the browser; drive the
  real per-channel servo; survive reboot. (Parallel multi-channel drive followed in v0.4.0, ADR 0010.)

## Phase 3 — WiFiManager + mDNS + OTA — RETIRED (folded into Phase S / S2)
- Captive-portal provisioning + mDNS + custom OTA shipped in Phase S; in-place WiFi change now lives
  in **System > WiFi**. No separate release.

## Phase 4 — MQTT / Home Assistant covers (v0.4.0) ☑
- **Objective:** HA cover entities per shutter, driving real servos.
- **Config done in v0.2.0** (broker connection, HA discovery, ADR-0005 command structure).
- **What we built (v0.4.0):** per-shutter `cover` + six `button` entities via MQTT discovery
  (re-published automatically on any shutter config change, deleted entities cleaned up); the
  `<base>/cover/<id>/{set,position/set,cmd}` handlers wired to each shutter's calibrated
  endpoints/favourites on its own channel; retained `position`/`state` publishing that also tracks
  web-UI moves; **concurrent per-channel drive** ([ADR 0010](decisions/0010-concurrent-servo-drive.md))
  so scenes move all shutters simultaneously; a live per-shutter **Topics** map on the MQTT page.
  Calibration-card commands (`goto_us`, `save:open`/`save:close`, raw-µs readback) stay
  deferred to Phase 8.
- **Exit criteria:** ☑ verified on hardware (2026-07-09, MQTT Explorer + HA) — covers appear and
  control the servo, jog buttons and Daylight/Privacy presets work, state/position topics track
  as expected.

## Phase 4b — Home Assistant Lovelace operating card (v0.4.x) ☑
- **Objective:** a purpose-built everyday dashboard tile for the shutters.
- **What we built:** `shutter-hub-card` — a custom Lovelace **frontend** card (plain custom
  element, registered as a Lovelace resource — **not** a HACS integration, see ADR-0007): 1–6 named
  shutters side by side with a live slat glyph; **group mode** (one Open/Close/Daylight/Privacy bar
  for all) that flips to **individual mode** (slider + buttons scoped to a selected shutter).
- **Spec:** [ha-lovelace-card.md](ha-lovelace-card.md) — entity model, config schema, card layout.
- **Prerequisites:** Phase 4 cover/button discovery.
- **Status (v0.4.2):** shipped — [`ha-card/shutter-hub-card.js`](../ha-card/shutter-hub-card.js),
  deployed to the *My Home › Shutters* dashboard as an inline Lovelace resource: group + per-shutter
  Open/Close/Daylight/Privacy and a manual position slider.
- **Exit criteria:** ☑ control card drives all/one shutter and follows the HA theme.
- The **calibration card** originally bundled in this phase is split out to **Phase 8 (optional)**
  together with the firmware commands it needs.

## Phase 5 — HomeKit (v0.5.0–v0.7.2) ☑
- **Objective:** native Apple Home control.
- **What we build:** HomeSpan bridge exposing one Window Covering per shutter; Siri.
- **Status:** ☑ **paired and working.** The HomeSpan bridge in
  [HomeKit.cpp](../firmware/src/HomeKit.cpp) runs — one Window Covering accessory per shutter,
  driving the same `ServoController` slots as MQTT — and shutters control from the Home app with
  changes syncing both ways (Home ↔ HA). Pairing was blocked through v0.6.x by a subtle defect: the
  fix landed in **v0.7.0** once the root cause was found — HomeSpan 1.9.1's mDNS hostname self-check
  uses `sscanf(hostName,"%m…")`, and **newlib-nano doesn't implement `%m`**, so the bridge hit its
  `while(1) PROGRAM HALTED` before advertising `_hap._tcp` or opening port 1201. It's fixed by a
  vendored HomeSpan patch (`firmware/patches/`, re-applied to every build). Earlier v0.5.1–v0.5.4
  fixes (reliable reboot via `esp_timer`; HomeSpan on its own FreeRTOS task; main-thread mDNS init)
  each removed a real defect on the way there.
  Pinned to `HomeSpan @ ~1.9.1` (last line supporting arduino-esp32 core 2.0.9). Coexistence: HAP on
  port 1201 (web server keeps 80), mDNS hostname pinned to the device name, WiFi stays with
  WiFiManager, QR id `SHUT`. Setup code default **748-88-377**. Uncalibrated shutters still operate
  via the servo envelope (MVP). **All HomeKit settings apply at boot** — the tab has a *Reboot to
  apply* button, and a WARN watchdog flags a stalled bridge. Flash is ~90 % of the app partition
  (HomeSpan pulls in HAP/SRP crypto) — Phase 6 fits the remaining headroom.
- **Exit criteria:** ☑ shutters controllable from the Home app and Siri, alongside HA — **met (v0.7.0)**.
  Confirmed on hardware: the bridge is discovered under *Add Accessory*, pairs, and drives the
  shutters; the dashboard reports the paired state correctly (fixed v0.7.2).

## Phase 6 — Light sensor + solar logic (v0.6.0–v0.6.2) ☑
- **Objective:** automatic heat protection.
- **Built in three ordered steps**, each independently useful:
  - **6a — firmware + web UI.** Real `LightSensor` VEML7700 driver on a **dedicated `Wire1` bus**
    (pins configurable, default SDA 25 / SCL 26 — [ADR 0011](decisions/0011-dedicated-sensor-i2c-bus.md),
    which reverses the old "shared bus" assumption); `SolarLogic` trip/clear state machine with
    dwell timers; a new **Solar** page (`/api/solar`, `/api/solar/simulate`) with a **simulate-lux
    slider** so the whole feature is testable before the sensor exists.
  - **6b — MQTT/HA.** Illuminance sensor, solar-state sensor, `Solar automation` switch, and two
    **writable `number`** entities for the trip/clear lux thresholds (the write-back hook Phase 8b
    needs). Clear ≥ trip is rejected — inverted hysteresis oscillates.
  - **6c — Lovelace card.** Optional solar toggle + lux caption in the group header
    (`solar_switch` / `solar_lux` / `solar_state` config keys; absent ⇒ card unchanged).
- **Follow-ups shipped in the same phase:**
  - **v0.6.1 — the sensor bus became a setting** ([ADR 0012](decisions/0012-selectable-sensor-i2c-bus.md)).
    The VEML7700 can keep its dedicated `Wire1` (default) or **share the PCA9685's `Wire`**. A
    dedicated bus needs a second I²C controller, so on a one-controller chip (the ESP32-C3) the
    preference is clamped to shared — which is what made solar work on the C3 at all. Also added the
    installation guide, user guide, and pinout reference.
  - **v0.6.2 — Info-page hardware table** (every device, its bus, pins, address/channel) plus a
    **Brightness (0–100 %)** sensor: `20 × log10(clamp(lux, 1, 100000))`, one lux decade per 20
    points. **Display-only** — the state machine still trips on raw lux, which the log curve
    compresses (30–60 k lx ⇒ 90–96 %).
- **Actions are five-valued**, not four: **Open · Closed · Daylight · Privacy · Do nothing**.
  `Do nothing` advances the state but moves nothing — the default clear action, so a trip to
  Privacy isn't undone automatically; both set to `Do nothing` = pure sensor/reporter mode.
- **Manual override:** a user move (web recall, MQTT set/position/jog/recall) suspends automation
  on **that** shutter for 2 h; the hub-wide state keeps tracking the light.
- **UI mockup:** [diagrams/solar-page.svg](diagrams/solar-page.svg) — dark-theme wireframe of the
  Solar page: Status (lux + simulate slider), Sensor (Wire1 pins + detect pill), Sensitivity, Actions.
- **Prerequisites:** Phase 5's HomeSpan flash cost known and budgeted (the bridge is built and
  pairing works), Phase 2 calibration (the presets the targets recall).
- **Exit criteria:** ☑ high lux drives every calibrated shutter to the bright target and the clear
  action applies per the dwell timers; lux + state reach HA; thresholds writable from HA. The
  simulate-lux slider exercises the whole path end-to-end from the Solar page.

## Phase 8b — HA-side threshold calibration (optional)
- **Objective:** stop guessing the trip/clear lux — recommend them from what the room actually saw.
- **Approach (no firmware work):** the lux sensor already records to Home Assistant's long-term
  statistics. A calibration card reads ~7–14 days via `recorder/statistics_during_period`, finds
  the sunny-day peak, and proposes **trip ≈ 75%** and **clear ≈ 40%** of it. *Apply* writes the two
  `number` entities shipped in 6b, which push straight into hub NVS.
- **Why HA-side:** the history, the statistics API and the charting already exist there; the ESP32
  has neither the flash nor the storage to keep 14 days of samples.
- **Exit criteria:** a card shows the observed daily light profile and one click adopts the
  recommended thresholds.

## Phase 7 — Production (v1.0.0)
- **Objective:** permanent install.
- **What we build:** hub enclosure (vented over XL4015, light window), per-shutter actuator
  enclosures, PCB/wiring loom, all 4 channels, watchdog/servo-timeout/brownout diagnostics.
- **Exit criteria:** four shutters running reliably behind the wall, OTA-updatable, "build once and
  leave running".

## Phase 8 — HA calibration card (optional)
- **Objective:** a setup-only calibration tile for a hidden/admin dashboard, so a shutter can be
  calibrated from HA without opening the hub web UI. **Optional** — the web UI Shutters page already
  covers calibration in full; build only if the convenience proves worth it.
- **What we build:** `shutter-hub-calibration-card` — shutter selector, µs scrub slider,
  exact-µs entry, and four save slots (Full open/close, Daylight, Privacy). **Set-and-go:** every
  position change drives the servo to that position so the real slat angle is visible before saving.
- **Spec:** [ha-lovelace-card.md](ha-lovelace-card.md) §4 — layout, interactions, and the firmware
  additions it needs.
- **Prerequisites:** firmware calibration transport (spec §4) — a `goto_us:<µs>` command, retained
  raw-µs readback, `save:open` / `save:close`, surfaced via MQTT discovery; plus `Shutters::MAX`
  raised from 4 → 6.
- **Exit criteria:** select a shutter, scrub or type µs → servo moves (set-and-go); save into the
  four slots persists to NVS (survives a FS OTA); never appears on the everyday dashboard.

---

## Open decisions

| # | Decision | Notes |
| - | --- | ----- |
| D1 | Final horn/arm ratio | Resolved by Phase 0 force test; start 10 mm horn + 20 mm arm. **Assumption to bench-validate (2026-07-08):** the rod end appears to need ~36 mm of rise *and* ~36 mm of horizontal excursion over 0→90° — an effective crank radius of ~36 mm (tip travels a ~51 mm chord), not 20 mm. If confirmed, a 1:1 parallelogram linkage needs a ~36 mm servo horn, and MG90D torque at that radius (~2.2 kg·cm → ~0.6 kg force) must be rechecked against the measured slat load. Use the v0.2.1 speed slider to run 0→90° slowly and measure actual rod displacement. |
| D2 | Servo connectors in hub | Grommet holes + strain relief (prototype) vs JST-XH (tidy/serviceable). [hardware-layout.md](hardware-layout.md) recommends grommets for the prototype, JST-XH panel breakout revisited at Phase 7. |
| D3 | Auto-OTA vs web-OTA only | **Resolved for web OTA:** the custom firmware+LittleFS uploader (core `Update.h`) shipped in v0.0.3, replacing the ElegantOTA scaffold. **Open:** whether to add `latest.json` auto-update checking. |
| D4 | Spare LM2596 | Superseded by XL4015; keep as spare or drop from BOM. |
| D5 | Voltage monitoring | Whether to populate GPIO34 servo-rail ADC for brownout telemetry. |
| D6 | Config editing UX | Resolved (ADR 0005): browser-owned web form, servos declared manually (no auto-scan); HA-side config is a later phase. |
| D7 | HA integration form | Resolved (ADR 0006): MQTT Discovery only — no published `custom_components`/HACS integration. Broker-free HTTP-native integration deferred as an optional path, not planned work. |
| D8 | HA card home | Resolved (ADR 0007): custom Lovelace **frontend** card (control + calibration), not stacked built-in cards. **Open sub-choice:** ship from a top-level `ha-card/` in this repo vs a companion `esp32-shutter-hub-card` repo for a clean HACS frontend listing — pick per how HACS should index it. |
| D9 | Servo position feedback | v0.3.0 handles the open-loop first-move jump in software (NVS position memory + assembly "home", [ADR 0009](decisions/0009-servo-position-memory.md)). **Open:** whether to ever add true feedback — tap the servo pots into an **ADS1115** (0x48) on the servo I2C bus (`Wire`, GPIO21/22), or move to feedback/serial-bus servos — to also kill the jump after a slat is moved by hand while unpowered. Deferred; revisit at Phase 7 if the residual proves annoying. |

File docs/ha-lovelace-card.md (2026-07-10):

# Home Assistant Lovelace card — build spec

Build-ready spec for the Shutter Hub dashboard cards. Companion to
[decisions/0007-ha-lovelace-card.md](decisions/0007-ha-lovelace-card.md) (why a custom
card) and [decisions/0005-mqtt-command-structure.md](decisions/0005-mqtt-command-structure.md)
(the entities/topics it binds to). Everything here is implementable as written; items
that need firmware are called out under **Firmware dependencies**.

Two cards are specified here, built in **separate phases**. **Status:** the operating card
([`ha-card/shutter-hub-card.js`](../ha-card/shutter-hub-card.js)) **shipped in v0.4.2**
(Phase 4b, done); the calibration card is a separate **optional Phase 8** because it needs
firmware that does not exist yet (see §4 and the plan).

| Card | Type | Status | Depends on |
| ---- | ---- | --- | --- |
| `shutter-hub-card` | Everyday control | **Shipped v0.4.2** (Phase 4b); optional solar header added v0.6.0 (Phase 6c) | Phase 4 covers/buttons; solar keys optional (§2a) |
| `shutter-hub-calibration-card` | Setup / calibration | **Phase 8 — optional** | Phase 4 **+** calibration transport (§4) |

---

## 1. Entity model (what the cards bind to)

Per shutter, from ADR-0005 MQTT discovery. `<id>` is the hub slug (e.g. `front_left`);
HA object-ids are prefixed by the hub name at discovery time.

Entity ids below are the **actual discovery names** (verified against a live hub).

| Entity | Example | Used by | Purpose |
| --- | --- | --- | --- |
| `cover.<hub>_<id>` | `cover.shutter_hub_shutter_1` | both | position 0–100, open/close/stop |
| `button.<hub>_<id>_daylight` | `button.shutter_hub_shutter_1_daylight` | control card | recall Daylight preset |
| `button.<hub>_<id>_privacy` | `button.shutter_hub_shutter_1_privacy` | control card | recall Privacy preset |
| `button.<hub>_<id>_jog_open` | — | (optional) | nudge open one step |
| `button.<hub>_<id>_jog_close` | — | (optional) | nudge close one step |
| `button.<hub>_<id>_save_daylight` | — | calibration | store current angle → Daylight |
| `button.<hub>_<id>_save_privacy` | — | calibration | store current angle → Privacy |
| `sensor`/`number` (calibration) | see §4 | calibration | raw µs read + set-and-go |

The **default card never needs raw µs** — it works entirely in cover position % plus
the four recall/open/close actions.

**Hub-wide solar entities** (Phase 6, v0.6.0+) — one set per hub, not per shutter. Optional: the
control card binds them only if configured (§2a).

| Entity | Example | Used by | Purpose |
| --- | --- | --- | --- |
| `switch.<hub>_solar_automation` | `switch.shutter_hub_solar_automation` | control card | enable/disable trip-clear automation |
| `sensor.<hub>_light_level` | `sensor.shutter_hub_light_level` | control card | **raw lux** — the value the card captions |
| `sensor.<hub>_solar_state` | `sensor.shutter_hub_solar_state` | control card | `idle`/`counting-trip`/`tripped`/`counting-clear` |
| `sensor.<hub>_brightness` | `sensor.shutter_hub_brightness` | — | 0–100 % human gauge; **display-only, not bound** |
| `number.<hub>_solar_trip_lux` | — | (Phase 8b) | writable trip threshold, lux |
| `number.<hub>_solar_clear_lux` | — | (Phase 8b) | writable clear threshold, lux |

---

## 2. Card config schema + editor

```yaml
type: custom:shutter-hub-card
title: Living room shutters        # optional; header text
shutters:                          # 1–6 entries, order = display order
  - name: Left                     # display name (defaults to cover friendly_name)
    entity: cover.shutter_hub_front_left
  - name: Centre
    entity: cover.shutter_hub_front_centre
  - name: Right
    entity: cover.shutter_hub_front_right

# Solar heat protection — all optional; omit for a no-sensor install
solar_switch: switch.shutter_hub_solar_automation
solar_lux: sensor.shutter_hub_light_level
solar_state: sensor.shutter_hub_solar_state
```

**Visual editor** (`getConfigElement` + `getStubConfig`):

- a repeatable row list — **add / delete / drag-reorder**; enforce **1 ≤ rows ≤ 6**;
- each row: a text field (name) + an entity picker filtered to `cover.*`;
- `getStubConfig` pre-fills any `cover.*` entities whose object-id matches the hub
  prefix, so dropping the card on a board is near-zero-config.

The calibration card takes the **same `shutters` list** (so the picker/reorder logic is
shared) plus per-shutter references to the calibration entities from §4.
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

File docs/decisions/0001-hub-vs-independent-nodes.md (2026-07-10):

# 0001 — Shutter Hub vs. Independent ESP32 Nodes

- **Status:** Accepted
- **Date:** 2026-07-07

## Context

Two topologies were considered for controlling the four Front Room shutters:

1. **Independent nodes** — each shutter gets its own ESP32 + servo, identical firmware,
   config-only differences.
2. **Shutter Hub** — one ESP32 drives all four servos over a short cable loom; actuator modules
   are mechanical-only.

The four shutters are in a **single room, physically close together**.
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

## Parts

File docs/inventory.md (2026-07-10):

# Inventory & Bill of Materials

Starting-state facts and parts the build assumes. Status: **⬤ ordered/in hand · ○ to source**.

## Shutters (existing — the thing being automated)

| Fact | Value |
| ---- | ----- |
| Panels | 4 (Front Room: Left, Left Centre, Right Centre, Right) |
| Panel width | ~450 mm |
| Slats per panel | 11 |
| Slat height | ~75 mm (3") |
| Material | lightweight wood or PVC blades, plastic tilt linkage |
| Tilt mechanism | one vertical tilt rod at the frame edge, moves all 11 slats |
| Replacing | Zemismart JM36/JC601 all-in-one Zigbee/battery tilt driver |
| Expected tilt-rod force | < 1 kg (to confirm — Phase 0 force test) |

## Electronics

| Part | Role | Status | Notes |
| ---- | ---- | --- | ----- |
| ESP32-D DevKit | Hub controller | ⬤ (existing stock) | 16 LEDC channels; two I2C controllers ([pinout.md](pinout.md)) |
| PCA9685 | 16-ch servo driver | ⬤ | I2C 0x40 on `Wire` — **SDA GPIO21 / SCL GPIO22**; servos on CH0–3 |
| MG90D digital metal-gear servo ×4 | Tilt actuators | ⬤ | ~2 kg·cm, ~13–14 g, 4.8–6 V |
| VEML7700 | Ambient light sensor | ⬤ | I2C 0x10; own `Wire1` by default — **SDA GPIO25 / SCL GPIO26** — or shared with the PCA9685 ([ADR 0012](decisions/0012-selectable-sensor-i2c-bus.md)); 0–120,000 lux |
| USB-C PD charger (30 W+) | Mains source | ⬤ | |
| AITRIP PD trigger board | PD → 12 V | ⬤ | Set to 12 V |
| XL4015 buck converter (~5 A) | 12 V → **5.1 V** | ⬤ (ordered) | Replaces LM2596; large heatsink, screw terminals |
| 1000–2200 µF electrolytic (≥10 V) | Servo-rail bulk cap | ⬤ | Near PCA9685 V+ |
| LM2596 buck | (spare / superseded) | ⬤ | Kept as spare — see plan D4 |

## Mechanical / linkage

| Part | Role | Status | Notes |
| ---- | ---- | --- | ----- |
| M2 × 50 mm ball-link pushrod | Servo → tilt rod | ⬤ | Link rod 50 mm; total adj. 75–85 mm; **hole-to-hole 68–78 mm**; 304 stainless + nylon ends |
| M2 × 60 mm ball-link pushrod | Backup length | ○ | A couple for mounting flexibility |
| Servo horns (8 / 10 / 12 mm holes) | Adjustable leverage | ○ | Start at 10 mm |
| 3D-printed shutter arm (holes 15/20/25 mm) | Adjustable leverage | ○ (to print) | Start at 20 mm |
| 3D-printed servo test bracket | Phase 0 proving | ○ (to print) | |
| Hub enclosure (printed) | Wall box, vented over XL4015, light window | ○ (to design) | |
| Actuator enclosures ×4 (printed) | Per-shutter modules | ○ (to design) | ~30×20×15 mm visible |

## Wiring

- Servo outputs: 3-wire (+5 V / GND / PWM) per channel.
- Connectors: grommet holes + strain relief (prototype) or JST-XH (tidier) — plan D2.
- **Common ground** across ESP32, PCA9685, and all servos.

## Power budget (worst case)

| Load | Current |
| ---- | --- |
| ESP32-D | ~0.25 A |
| PCA9685 | ~0.05 A |
| 4 × MG90D (all moving) | 2–3 A peak |
| Headroom on XL4015 (~5 A) | ~1 A+ |

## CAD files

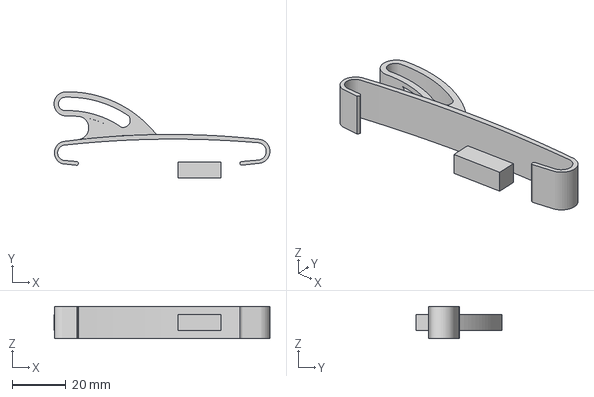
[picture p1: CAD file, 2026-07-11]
cad/slat-hook/slat-clip-crank.3mf
80.6 x 32.2 x 12.0 mm

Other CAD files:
cad/slat-hook/slat-clip-crank.stl

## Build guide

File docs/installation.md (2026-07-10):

# Installation Guide — ESP32 Smart Shutter Hub

Repository: <https://github.com/rhamblen/esp32-shutter-hub>

Everything needed to go from a bare ESP32 to four calibrated shutters answering to Home Assistant,
Apple Home, and a browser. Follow the steps in order — each one assumes the previous one worked.

Day-to-day operation is covered separately in [user-guide.md](user-guide.md). The parts list is in
[inventory.md](inventory.md); the physical build is in [hardware-layout.md](hardware-layout.md).

---

## Prerequisites

| Requirement | Detail |
| --- | --- |
| Hardware | ESP32-D DevKit, PCA9685, MG90D servos, VEML7700, 5.1 V supply — see [inventory.md](inventory.md) |
| Assembled | Servos wired to PCA9685 CH0–3, PCA9685 on GPIO21/22, VEML7700 on GPIO25/26 |
| WiFi | 2.4 GHz network (the ESP32 has no 5 GHz radio) |
| Flashing | A USB data cable, plus **either** [PlatformIO](https://platformio.org/) **or** [NodeMCU-PyFlasher](https://github.com/marcelstoer/nodemcu-pyflasher) / `esptool` |
| Home Assistant *(optional)* | A working install with the **MQTT integration** configured against a broker (e.g. Mosquitto add-on) |
| Apple Home *(optional)* | An iPhone/iPad and a HomeKit hub (HomePod or Apple TV) if you want remote access |

Home Assistant and Apple Home are both optional. The hub is fully usable from its own web UI alone.

---

## Step 1 — Get the firmware

Two routes. Downloading a release is the normal one; building from source is for when you have
changed the code.

### Option A — download a prebuilt release (recommended)

Go to the [Releases page](https://github.com/rhamblen/esp32-shutter-hub/releases) and download the
assets for the **`esp32d-pca9685`** variant (that is the real four-shutter hub; `esp32d-direct` is a
single-servo bench build). A release carries three files per variant:

> `esp32c3-*` bins are also published, but they are **untested engineering builds**. They carry the
> same firmware — the servo-pin whitelist is now C3-safe (v0.7.2) and solar works on the C3's shared
> I²C bus — but the C3 has fewer PWM channels and has not been verified on real hardware. **Use an
> ESP32-D** for a real build. [pinout.md](pinout.md) has the detail.

| File | What it is | When you need it |
| ---- | --- | --- |
| `shutter-hub-esp32d-pca9685-full-vX.Y.Z.bin` | Bootloader + partitions + app, merged | First USB flash only |
| `shutter-hub-esp32d-pca9685-ota-vX.Y.Z.bin` | App only | Every later update, over WiFi |
| `shutter-hub-esp32d-littlefs-vX.Y.Z.bin` | The web UI filesystem | With the first flash, and whenever the UI changes |

### Option B — build from source

```bash
git clone https://github.com/rhamblen/esp32-shutter-hub
cd esp32-shutter-hub/firmware
pio run -e esp32d-pca9685              # firmware  -> .pio/build/esp32d-pca9685/firmware.bin
pio run -e esp32d-pca9685 -t buildfs   # web UI    -> .pio/build/esp32d-pca9685/littlefs.bin
```

See [firmware/README.md](../firmware/README.md) for the full variant table and the `merge-bin`
recipe that produces the `-full-` image.

---

## Step 2 — First flash over USB

This is the **only** time you need a cable. Plug the ESP32 into USB.

**With PlatformIO** (source checkout):

```bash
pio run -e esp32d-pca9685 -t upload      # firmware
pio run -e esp32d-pca9685 -t uploadfs    # web UI filesystem — do not skip this
pio device monitor                       # optional: watch the boot log at 115200 baud
```

**With a downloaded release** (`esptool`):

```bash
esptool --chip esp32 write_flash 0x0 shutter-hub-esp32d-pca9685-full-vX.Y.Z.bin
esptool --chip esp32 write_flash 0x290000 shutter-hub-esp32d-littlefs-vX.Y.Z.bin
```

`0x290000` is where LittleFS lives in the ESP32 default partition table, which this firmware uses.
The filesystem image is the same for every variant — only the firmware differs.

In NodeMCU-PyFlasher, select the `-full-` bin and flash it to address `0x0`.

> **If you flash only the firmware and not the filesystem**, the hub boots into a plain embedded
> recovery page that offers nothing but an OTA uploader. That is by design — upload the LittleFS
> image from that page and the real UI appears. It is not a failed flash.

---

## Step 3 — Join it to your WiFi

Nothing is compiled into the binary, so the same image works on anybody's network.

1. On first boot the hub raises an access point called **`Shutter-Hub-Setup`**. Join it from a phone
   or laptop.
2. A captive portal opens automatically. If it does not, browse to `http://192.168.4.1`.
3. Pick your 2.4 GHz network, enter the password, save.
4. The hub reboots and joins your network. Credentials are written to **NVS**, a flash partition that
   OTA updates never touch — you do this once, ever.

Now open **`http://shutter-hub.local`**. If mDNS does not resolve on your machine (common on some
Windows and Android setups), find the hub's IP in your router's DHCP table and use that instead.

You should land on the **Dashboard**, showing firmware version, chip, variant, IP, and uptime.

Scroll down to **Hardware & wiring**. It lists every device the firmware expects: the PCA9685 with
its I²C bus, pins and address, a row per shutter with its channel, and the VEML7700 with its bus,
pins, and whether it is answering. Check it against the board now — a wrong pin here is a fault you
would otherwise chase through the next three steps. On a direct-GPIO build the table shows the single
servo's signal pin and no channels, because there are none. Full map in [pinout.md](pinout.md).

---

## Step 4 — Prove the servos move

Before calibrating anything, confirm the power chain and the PCA9685 are alive. Go to
**Servo test**, pick channel 0, and sweep the angle slider. The servo should track it smoothly.

If nothing moves, the fault is almost always in this list:

| Symptom | Likely cause | Fix |
| --- | --- | --- |
| No movement, no twitch | PCA9685 V+ not powered | The 5.1 V servo rail is separate from the ESP32's 3.3 V logic — both must be live |
| ESP32 reboots when the servo moves | Brown-out from inrush | Add the bulk capacitor across PCA9685 V+ / GND |
| Servo buzzes, drifts, never settles | No common ground | Tie the buck converter's ground to the ESP32's ground |
| Info page shows `direct` not `pca9685` | Wrong build variant flashed | Reflash the `esp32d-pca9685` image |
| Wrong blind moves | Shutter assigned to the wrong channel | Compare the channel rows on Info ▸ Hardware & wiring against the servo leads |
| Info ▸ Hardware & wiring shows the wrong SDA/SCL | Bus pins reconfigured, or bus shared | Set the servo bus pins on **Servo test**, the sensor bus on **Solar** |

---

## Step 5 — Define and calibrate each shutter

This is the step that takes real time, and the one nothing else works without. Everything saves
instantly to NVS.

Open **Shutters** and, for each blind:

1. **Add shutter.** Give it a friendly name ("Front room – left") and assign its **PCA9685 channel**
   (0–3). The name generates a slug used as the MQTT id — rename freely, but note that renaming
   changes the entity ids in Home Assistant.
2. **Find fully closed.** Use **slow close** (`◀◀`) to run the servo down, **stop** (`⏸`) near the
   endpoint, then **nudge** (`⏮`/`⏭`) in 5 µs steps until the slats are just closed without the servo
   straining. Press **Save current** on the *Full close* row.
3. **Find fully open.** Same, in the other direction. **Save current** on *Full open*.
4. **Set the favourites.** Jog to a comfortable daytime angle → **Save current** on *Daylight*. Jog to
   a slats-closed-but-not-jammed privacy angle → **Save current** on *Privacy*.
5. **Test all four.** Press **Go** on each row and watch it land where you expect.

> **Never drive a servo past mechanical stall.** If a servo hums and stays hot at an endpoint, it is
> pushing against the linkage. Back the endpoint off by 25 µs and re-save. Stalled MG90Ds burn out.

**Invert position scale** is on the shutter's detail card. Leave it off unless the mechanics run
backwards: the Home Assistant convention is 0 % = closed, 100 % = open, and the card and HomeKit both
assume it.

Repeat for all four blinds. Positions survive reboots and OTA updates, so the first move after a
power cut slews rather than snapping.

---

## Step 6 — Connect Home Assistant (optional)

The hub speaks MQTT and publishes Home Assistant discovery messages, so there is no custom
integration to install and no YAML to write.

1. In Home Assistant, make sure the **MQTT integration** is set up against your broker. Note the
   broker's IP, port, and a username/password.
2. In the hub's web UI, open **MQTT → Broker** and fill in:

   | Field | Value |
   | ----- | ----- |
   | Broker Address | Your broker's IP, e.g. `192.168.1.60` |
   | Port | `1883` |
   | Client ID | Leave blank for `shutter-hub-<mac>` |
   | Username / Password | Your broker credentials |
   | Base Topic | `shutter-hub` |
   | Home Assistant MQTT Discovery | **on** |
   | Enable MQTT | **on** |

3. **Save & Apply changes.** The status pill turns green when the broker connection is up.
4. In Home Assistant, look under **Settings → Devices & Services → MQTT**. One device appears, with:

   | Entity | Role |
   | ------ | ---- |
   | `cover.*` (one per shutter) | Open / close / stop, position 0–100 % |
   | `button.*_daylight`, `button.*_privacy` | Recall the saved presets |
   | `button.*_jog_open`, `button.*_jog_close` | Nudge 25 µs |
   | `button.*_save_daylight`, `button.*_save_privacy` | Overwrite a preset with the current position (diagnostic) |
   | `sensor.*_light_level` | Lux from the VEML7700 |
   | `sensor.*_solar_state` | Solar state machine: idle / armed / tripped |
   | `switch.*_solar_automation` | Enable/disable solar heat protection |
   | `number.*_trip_lux`, `number.*_clear_lux` | The two thresholds, writable from HA |

The **MQTT → Topics** tab shows the live topic map if you want to drive the hub from something other
than Home Assistant. Commands go to `shutter-hub/cover/<id>/set` and
`shutter-hub/cover/<id>/position/set`; retained state comes back on `.../state` and `.../position`.

**Troubleshooting**

| Symptom | Likely cause | Fix |
| --- | --- | --- |
| Pill stays red | Bad credentials, or broker not reachable | Check the **Logs** page — the MQTT error is logged verbatim |
| Connects, but no entities in HA | Discovery off, or HA's discovery prefix changed | Turn on **Home Assistant MQTT Discovery**; HA's prefix must be the default `homeassistant` |
| A deleted shutter still shows in HA | Retained discovery config on the broker | Deleting a shutter clears it; if it lingers, delete the device in HA |
| Covers show as unavailable | Hub offline, or LWT fired | Availability is `shutter-hub/status`; check the hub is powered and on WiFi |

---

## Step 7 — Install the Lovelace card (optional)

The [`ha-card/`](../ha-card/) directory holds `shutter-hub-card.js`, a single plain custom element —
no build step, no HACS requirement.

1. Copy `shutter-hub-card.js` to `/config/www/shutter-hub-card.js` on your Home Assistant machine.
2. **Settings → Dashboards → ⋮ → Resources → Add resource**, URL `/local/shutter-hub-card.js`, type
   **JavaScript Module**.
3. Hard-refresh the browser (Ctrl-Shift-R).
4. Add a manual card to a dashboard:

```yaml
type: custom:shutter-hub-card
title: Shutters
shutters:
  - entity: cover.shutter_hub_front_room_left
    name: Left
  - entity: cover.shutter_hub_front_room_left_centre
    name: Left Centre
  - entity: cover.shutter_hub_front_room_right_centre
    name: Right Centre
  - entity: cover.shutter_hub_front_room_right
    name: Right
```

Use **Developer Tools → States** to get your real `cover.*` entity ids — they follow your device and
shutter names. The card derives the Daylight/Privacy button entities from each cover id; if your
naming differs, set `daylight:` and `privacy:` explicitly per shutter. See
[../ha-card/README.md](../ha-card/README.md) for the full option list.

---

## Step 8 — Pair with Apple Home (optional)

The hub runs a [HomeSpan](https://github.com/HomeSpan/HomeSpan) bridge: each shutter appears in the
Home app as its own **Window Covering**, alongside — not instead of — the Home Assistant entities.

> **Optional.** HomeKit adds nothing you can't already do from Home Assistant or the web UI — skip it
> if you don't use Apple Home. If you do: enable HomeKit on the System ▸ HomeKit tab, **reboot** (the
> pairing verifier is baked at boot), then add the accessory with the setup code shown on that tab.
> Changes then sync both ways between Apple Home and Home Assistant.

1. **System → HomeKit.** Set a **Bridge name** and an 8-digit **Setup code** (default `748-88-377`;
   **⟳ Random code** generates a fresh one).
2. **Save changes**, then **↻ Reboot to apply**. HomeKit changes — enabling it, the code, the name,
   adding or removing shutters — take effect *only* after a reboot, because the pairing verifier is
   computed at boot.
3. After the reboot, the page shows the bridge status and a **pairing QR code**.
4. In the Home app: **+ → Add Accessory → More options…**, or scan the QR with the iPhone camera.
5. All shutters appear at once as one bridge. Assign them to rooms.

If you add a shutter later, reboot the hub so HomeSpan republishes its accessory list.

---

## Step 9 — Set up solar heat protection (optional)

The VEML7700 sits on its **own I²C bus** (`Wire1`, SDA GPIO25 / SCL GPIO26 by default) so a fault on
the sensor lead cannot take down the PCA9685 servo bus on GPIO21/22 — see
[ADR 0011](decisions/0011-dedicated-sensor-i2c-bus.md) and [pinout.md](pinout.md).

> **Dedicated sensor bus needs two I²C controllers.** The ESP32-D has two, so the VEML7700 gets its
> own `Wire1`, fault-isolated from the servo bus. The **ESP32-C3 has one**, so on a C3 the sensor
> shares the PCA9685's `Wire` — solar still works, but you lose that fault isolation; the web UI clamps
> the C3 to the shared bus automatically ([ADR 0012](decisions/0012-selectable-sensor-i2c-bus.md)).

> **Testing without the sensor:** the simulate-lux slider on the Solar page drives the whole trip/clear
> state machine and the HA entities, so you can verify the automation before (or without) wiring a
> VEML7700.

Open the **Solar** page.

1. **Sensor card.** Confirm the SDA/SCL GPIOs match your wiring (defaults 25 / 26 — avoid GPIO34–39,
   which are input-only and cannot drive I²C). Toggle **Enable sensor**. The detection pill should
   go green and the **Status** card should start reporting lux.
2. **Sensitivity card.** Set the thresholds:

   | Field | Meaning | Sensible start |
   | ----- | ------- | -------------- |
   | Trip when lux above | Direct-sun level for your window | `60000` |
   | …held for (minutes) | Dwell before acting | `10` |
   | Clear when lux below | Sun has moved off | `30000` |
   | …held for (minutes) | Dwell before releasing | `20` |

   The gap between trip and clear is **hysteresis** — it is what stops a passing cloud from flapping
   the shutters. Keep *clear* comfortably below *trip*.

3. **Actions card.** Choose where the shutters go **when bright** (typically `Privacy` or `Closed`)
   and **when clear**. Any action can be **Do nothing** — a "do nothing" clear leaves the slats where
   the trip put them, and setting both to **Do nothing** turns the hub into a pure light monitor that
   still reports to Home Assistant.
4. Toggle **Solar automation** on and **Save & Apply changes**.
5. **Test it without waiting for the sun.** Drag **Simulate lux** above your trip threshold, press
   **Use simulated**, and watch the state advance through *armed* to *tripped* — the dwell timer is
   real, so give it the configured minutes. Press **Use live sensor** when you are done.

**Manual override:** moving a shutter by hand — from the web UI, Home Assistant, or Apple Home —
suspends solar automation *on that shutter only* for **2 hours**. The rest keep automating. This is
deliberate: if you overrode the automation, you meant it.

Calibrate the thresholds against your own window over a few sunny days. Lux through glass varies
enormously with orientation, glazing, and season.

---

## Step 10 — Lock it down

**System → Security.** Turn on **Enable Web Authentication** and set a username and password
(defaults to `admin`). The hub is on your LAN with no transport encryption — HTTPS on-device is
listed as planned and is not available — so treat the web UI as trusted-network-only. Do not expose
`shutter-hub.local` to the internet.

---

## Updating later (OTA)

After the first USB flash, every update goes over WiFi from the **OTA Update** page.

1. Download (or build) the new `-ota-` firmware bin, and the `-littlefs-` bin if the release notes
   say the web UI changed.
2. **If both changed, upload the filesystem first** — the firmware upload reboots the board.
3. **Upload Firmware** with the app bin. The page shows a live upload log, then the hub reboots.

Your WiFi credentials, MQTT settings, shutter definitions, calibration, favourites, HomeKit pairings,
and solar thresholds all live in NVS and are untouched by either upload.

**Recovering a bad flash:** if the hub is unreachable, hold it in reach of a USB cable and reflash the
`-full-` image at `0x0`. NVS survives that too. To wipe settings deliberately, use **System → Quick
Actions → Reset config**, or **Reset WiFi** to drop back into the `Shutter-Hub-Setup` portal.

---

## Troubleshooting index

| Symptom | Where to look |
| --- | --- |
| Web UI is a bare recovery page | LittleFS image never flashed — Step 2 |
| `shutter-hub.local` does not resolve | mDNS; use the IP from your router — Step 3 |
| Servos do not move | Power chain and common ground — Step 4 |
| A servo hums and gets hot | Endpoint driven past stall — Step 5 |
| Shutter opens when HA says close | **Invert position scale** — Step 5 |
| No entities in Home Assistant | Discovery toggle and broker credentials — Step 6 |
| Apple Home cannot find the bridge | Known open issue — Step 8 |
| Solar never trips | Thresholds, or automation switch off — Step 9 |
| Anything else | **Logs** page — a live WebSocket stream of everything the firmware logs |

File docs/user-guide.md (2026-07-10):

# User Guide — ESP32 Smart Shutter Hub

Day-to-day operation, once the hub is built, flashed, and calibrated. If you have not done that yet,
start at [installation.md](installation.md).

> **About the screenshots.** The web-UI pictures below are design mockups, not captures of a running
> device. They show the layout and the controls in the positions you will find them, but wording,
> colours, and version numbers on the real screens may differ — and will drift as the firmware moves
> on. Trust the device in front of you over the picture.

The hub has **four faces**, and they all drive the same servos and stay in sync with each other:

| Face | Address | Best for |
| ---- | --- | --- |
| **Web UI** | `http://shutter-hub.local` | Setup, calibration, diagnostics, OTA |
| **Home Assistant** | The MQTT device, or the Lovelace card | Automations, dashboards, voice |
| **Apple Home** | Window Covering accessories | Siri, iPhone, remote access |
| **Lovelace card** | A dashboard tile | Everyday tapping — the nicest of the four |

Move a shutter anywhere and every other face updates within a quarter-second. Retained MQTT state
means Home Assistant knows the right position even after a restart.

---

## The four positions

Every shutter carries four saved positions, set during calibration and stored in NVS:

| Position | Meaning | HA position |
| --- | --- | --- |
| **Full open** | Slats horizontal, maximum light | 100 % |
| **Daylight** | Comfortable daytime angle — light in, glare out | wherever you saved it |
| **Privacy** | Slats angled closed, light but no sightline | wherever you saved it |
| **Full close** | Slats fully shut | 0 % |

Open and Close are the endpoints of travel; Daylight and Privacy are named favourites anywhere in
between. Any position from 0–100 % is reachable with the slider — the four are just the ones worth
naming.

To change a favourite, jog the shutter to where you want it and press **Save current** on that row
in the web UI's **Shutters → Positions** card, or press the `button.*_save_daylight` /
`button.*_save_privacy` entity in Home Assistant.

---

## Using the Lovelace card

The card shows every configured shutter as a tile — a slat glyph whose angle tracks the real
position, plus its name and state.

**Group mode** is the default: the button bar and the position slider act on **all** shutters at
once. Tap **Open**, **Close**, **Daylight**, or **Privacy** and the whole bank moves together —
literally together, since each shutter drives its own PCA9685 channel concurrently rather than one
after another.

**Individual mode**: tap a tile and the buttons and slider scope to that shutter alone. Tap it again,
or press **Select all**, to go back to the group.

**Manual position**: the slider commands any angle from 0–100 %, for the times none of the four
presets is what you want.

**Stop** halts a move in flight.

---

## Using Home Assistant directly

Each shutter is a native `cover` entity, so everything Home Assistant knows how to do with covers
works: `cover.open_cover`, `cover.close_cover`, `cover.stop_cover`, `cover.set_cover_position`,
scenes, scripts, voice assistants, the standard more-info dialog.

A worked example — close the shutters to Privacy at sunset:

```yaml
alias: Shutters to privacy at sunset
triggers:
  - trigger: sun
    event: sunset
    offset: "-00:15:00"
actions:
  - action: button.press
    target:
      entity_id:
        - button.shutter_hub_front_room_left_privacy
        - button.shutter_hub_front_room_right_privacy
```

Pressing the preset buttons is preferable to `set_cover_position` with a hard-coded number: the
preset follows your calibration, so if you re-save Privacy the automation follows it without edits.

The hub also exposes, once per device rather than per shutter:

| Entity | Use |
| --- | --- |
| `sensor.*_light_level` | Lux — chart it, or trigger your own automations on it |
| `sensor.*_solar_state` | `idle` / `armed` / `tripped` |
| `switch.*_solar_automation` | Turn heat protection on and off from a dashboard |
| `number.*_trip_lux`, `number.*_clear_lux` | Adjust the thresholds without opening the web UI |

Those two `number` entities are the reason threshold tuning is comfortable: put them on a dashboard
beside a lux history graph and adjust while watching the room.

---

## Using Apple Home

> **Works as of v0.7.0.** Enable HomeKit on the System ▸ HomeKit tab, reboot, then add the accessory
> in Apple Home. HomeKit is entirely optional — if you leave it off, the web UI, Home Assistant, the
> Lovelace card and solar automation all work exactly the same. See
> [installation.md](installation.md#step-8--pair-with-apple-home-optional).

Each shutter is a **Window Covering** accessory. Ask Siri to "open the front room shutters", or drag
the slider in the Home app. Because the hub bridges through HomeSpan, the accessories appear
individually and can go in different rooms if that suits your layout. Changes made in Apple Home and
in Home Assistant stay in sync — move a shutter in one and the other follows.

Apple Home has no concept of your Daylight and Privacy presets — model them as Home app *scenes* that
set specific percentages, or trigger the Home Assistant buttons instead.

---

## Solar heat protection

> Works on any board. By default the sensor gets its **own I²C bus** so a fault on its lead can't
> disturb the servos. Chips with a single I²C controller (the ESP32-C3) instead **share** the
> PCA9685's bus — the Solar page picks this for you and explains why. See
> [ADR 0012](decisions/0012-selectable-sensor-i2c-bus.md).

The VEML7700 watches the light level. When lux stays **above** the trip threshold for the trip dwell,
the hub moves the shutters to your chosen bright-action position. When lux stays **below** the clear
threshold for the clear dwell, it moves them to the clear-action position.

The Solar page

The state machine reads:

| State | Meaning |
| ----- | --- |
| **idle** | Light is below the trip threshold; nothing pending |
| **armed** | Light is above the trip threshold, dwell timer counting |
| **tripped** | The bright action has fired; watching for the clear condition |

Two things are worth internalising.

**Hysteresis is the point.** Trip and clear are deliberately different numbers, and both have dwell
timers. Without that gap, a cloud crossing the sun would drive your shutters back and forth all
afternoon. If yours are twitchy, widen the gap or lengthen the dwells before you touch anything else.

**Manual override wins for 2 hours.** Move a shutter yourself — web UI, Home Assistant, Apple Home,
does not matter — and solar automation stops touching *that* shutter for two hours. The others carry
on. Then it resumes. Nothing to press, nothing to remember to undo.

**Do nothing** is a first-class action for both trip and clear. A "do nothing" clear leaves the slats
where the trip put them, which is often what you want on a west-facing window in summer. Setting both
to **Do nothing** turns the hub into a light monitor that reports to Home Assistant and moves nothing.

To tune the thresholds, watch `sensor.*_light_level` in Home Assistant across a few sunny days and
note the lux when direct sun actually hits the room. Set trip a little below that, and clear well
under it. The **Simulate lux** slider on the Solar page lets you rehearse the whole sequence at any
time — press **Use simulated**, drag it past the trip point, wait out the dwell, and watch the state
advance. **Use live sensor** returns to reality.

---

## Recalibrating

Shutters drift. Linkages settle, servo horns creep, someone leans on a blind. Recalibration takes a
minute per shutter and does not disturb anything else.

Open **Shutters**, pick the blind, use **slow close** / **stop** / **nudge** to land the endpoint
exactly where you want it, and press **Save current** on the row concerned. It writes to NVS
immediately — no save button, no reboot.

The Shutters calibration page

The transport controls, in the order you actually use them:

| Control | What it does |
| --- | --- |
| `◀◀` **slow close** / `▶▶` **slow open** | Run continuously at the speed slider's rate (5–120 °/s) |
| `⏸` **stop** | Halt where it is |
| `⏮` / `⏭` **nudge** | One step: 5 µs (Fine) or 25 µs (Coarse) |
| **Detach (release)** | Cut the PWM so the servo goes limp — for moving a blind by hand |

Watch the microsecond readout, not the percentage: percentage is derived from the endpoints you are
in the middle of changing.

**If a servo hums and gets hot at an endpoint**, it is stalling against the linkage. Back that
endpoint off by 25 µs and re-save. A stalled MG90D will cook itself.

---

## Reading the Logs page

**Logs** is a live WebSocket stream of everything the firmware logs — WiFi events, MQTT connect and
every message in and out, servo commands, solar state transitions, OTA progress. It is the first
place to look when something behaves oddly, and it is almost always conclusive: MQTT auth failures,
I²C sensor detection, and dropped WiFi all announce themselves plainly.

The stream is live only — nothing is persisted across a reboot.

---

## Routine maintenance

**Updating.** New releases install over WiFi from the **OTA Update** page. Upload the filesystem
image first if the release notes mention web-UI changes, then the firmware, which reboots the board.
Settings, calibration, and pairings survive. Full procedure in
[installation.md](installation.md#updating-later-ota).

**After a power cut**, the hub remembers where every servo was and slews to its first commanded
position rather than snapping to it. Nothing to do.

**Moving house, or changing router.** **System → WiFi** scans and reconnects in place. If the hub
cannot reach the old network at all, **System → Quick Actions → Reset WiFi** reboots it into the
`Shutter-Hub-Setup` captive portal, exactly as on first boot. Everything else is preserved.

**Reset config** wipes MQTT, security, HomeKit, and solar settings back to defaults. It does not
spare your shutter definitions — treat it as a last resort, and expect to recalibrate.

---

## When something is wrong

Start on the **Info** page. Beneath the device and network cards, **Hardware & wiring** lists every
device the firmware expects — the PCA9685 with its I²C bus, pins and address, a row per shutter with
its channel and whether it is calibrated, and the light sensor with its bus, pins, and whether it is
answering at `0x10`. It is the fastest way to tell a wiring fault from a configuration one. The same
card reports **HomeKit** as disabled, enabled-pending-reboot, active, or paired.

Everything in that table is set elsewhere — servo bus pins on **Servo test**, channels on
**Shutters**, the sensor bus on **Solar**. It shows what the hub believes; it does not change it.

| Symptom | First thing to check |
| --- | --- |
| One shutter unresponsive, others fine | Its PCA9685 channel assignment on the **Shutters** page; then the servo lead |
| All shutters unresponsive, web UI fine | The 5.1 V servo rail — the ESP32 runs happily on USB power alone while the servos have none |
| Shutter goes the wrong way | **Invert position scale** on that shutter's detail card |
| Position in HA disagrees with reality | Endpoints drifted — recalibrate |
| Solar never fires | **Solar automation** switch, then whether a manual move started a 2-hour override |
| Solar fires constantly | Trip and clear too close together; widen the gap and lengthen the dwells |
| Everything is unavailable in HA | The hub is offline — its MQTT last-will fired. Check power and WiFi |
| Web UI unreachable, hub apparently up | mDNS. Try the IP address from your router's DHCP table |

For anything not on that list, open the **Logs** page and reproduce the problem while watching.

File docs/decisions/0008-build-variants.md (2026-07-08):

# 0008 — Build variants (board × servo backend)

- **Status:** Accepted
- **Date:** 2026-07-08

## Context

The hub can drive its servos two ways: **directly from an ESP32 GPIO** (one actuator, LEDC PWM via
ESP32Servo — the Phase-1 bench rig) or through a **PCA9685** 16-channel I2C servo driver (the
multi-shutter target, ADR 0003). Both are live hardware paths we want to keep: the direct build is
the simplest way to prove one actuator with nothing but a dev board, and the PCA9685 build is the
production topology. On top of that the project targets two boards — the **ESP32-D** (primary) and a
deferred **ESP32-C3** (different pinout).

That is a 2 × 2 matrix. We need each combination to be **buildable, flashable, and identifiable** —
so an OTA `.bin` on disk, and the running device's info/OTA screens, unambiguously say which servo
hardware the firmware expects. Flashing a PCA9685 image onto a direct-wired board (or vice-versa)
should be obvious, not a silent mismatch.

## Decision

1. The servo backend is a **compile-time choice**, `-D USE_PCA9685=0|1`, selected per PlatformIO env.
   `ServoController` keeps one public API; only its hardware primitives (init, emit-µs,
   attach/detach, addressing) switch on the flag. The µs position core is shared.
2. Every build carries a **`FW_VARIANT`** string (`-D FW_VARIANT=\"esp32d-pca9685\"`) — `board`-`backend`.
   It is exposed at `/api/info` (`variant`, plus a `backend` of `gpio`|`pca9685`) and shown on the
   **Dashboard** and **OTA** screens, and it names the release artifacts:
   `shutter-hub-<variant>-{full,ota,littlefs}-vX.Y.Z.bin`.
3. **Four envs**, one per matrix cell:

   | Env | Board | Backend | Status |
   | --- | ----- | ------- | ------ |
   | `esp32d-direct` | ESP32-D | direct GPIO | active |
   | `esp32d-pca9685` | ESP32-D | PCA9685 | active (default) |
   | `esp32c3-direct` | ESP32-C3 | direct GPIO | deferred |
   | `esp32c3-pca9685` | ESP32-C3 | PCA9685 | deferred |

   `default_envs = esp32d-pca9685` (current focus). Only the ESP32-D envs are built day-to-day; the
   C3 envs are defined but excluded until a release brings them in (its pinout/I2C map differs).
   Releases build all four.
4. The **web UI is a single `data/` tree** — the Servo-test page reads `backend` from `/api/info` and
   renders the right addressing controls at runtime (signal-GPIO selector vs. I2C SDA/SCL + channel
   selector). No per-variant filesystem build; the LittleFS image is identical across variants.

## Rationale

- A compile-time flag (vs. a runtime setting) means the unused servo library isn't even linked, keeps
  the binary honest about what hardware it expects, and avoids a config that could point a build at
  hardware it wasn't built for.
- Naming the variant in the artifact and on-screen removes the single most likely field mistake —
  flashing the wrong servo topology — with zero runtime cost.
- Runtime-adaptive web pages keep one source of truth for the UI; the tiny cost is one `backend`
  branch in the Servo-test JS, far cheaper than a build-time page-assembly pipeline.

## Consequences

- Adding a board or backend is a new env + a `FW_VARIANT` string; no code fork.
- The PCA9685 build needs the I2C bus pins and a test channel — added to `AppConfig` (defaults SDA 21
  / SCL 22 / channel 0 for the ESP32-D) and settable from the Servo-test page.
- Release tooling now produces **up to four × three** bins; day-to-day only the two ESP32-D sets are
  regenerated (the C3 is deferred).
- `ServoController`'s single-servo, one-active-channel model is unchanged — parallel 4-channel drive
  remains a later phase (see [project-plan.md](../project-plan.md)).

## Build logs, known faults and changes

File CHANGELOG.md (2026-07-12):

# Changelog

All notable changes to this project are documented here. Format based on
[Keep a Changelog](https://keepachangelog.com); this project uses [SemVer](https://semver.org).
Phases map loosely to minor versions (Phase 1 → v0.1.0).

## [Unreleased]

### Added
- **STL export + one-click downloads.** [cad/slat-hook/slat-clip-crank.stl](cad/slat-hook/slat-clip-crank.stl)
  sits alongside the 3MF (identical geometry). The README and `cad/README.md` now carry a
  **Download the 3D-print files** table with direct `/raw/` links so the parts can be saved without
  navigating the repo tree.

### Documentation
Documentation-only audit against the v0.6.2 firmware. **No code, no behaviour, no version change.**

- **HomeKit status corrected everywhere.** Phase 5 is **built but unpaired** — the bridge boots and
  advertises, but no controller has ever completed pairing, and the work is parked. `project-plan.md`
  previously claimed pairing was *verified*, contradicting the README, `installation.md` and
  `user-guide.md`. The plan's status table now shows Phase 5 as ◐ with its exit criteria unmet, and
  `user-guide.md` leads its Apple Home section with the caveat rather than burying it.
- **Phase 6 marked ◐, not ☑** — the solar logic is built and exercised through the simulate-lux
  slider, but the physical VEML7700 is still not wired. The plan's own exit criteria already said so.
- **Lovelace card solar options documented** in [ha-card/README.md](ha-card/README.md) and
  [docs/ha-lovelace-card.md](docs/ha-lovelace-card.md) §2a — the `solar_switch` / `solar_lux` /
  `solar_state` keys shipped in v0.6.0 but appeared in neither, though `installation.md` points users
  at the card README for "the full option list". Includes the lux-vs-brightness distinction: the card
  captions **raw lux** because the state machine trips on raw lux, while `sensor.<hub>_brightness`
  (`20 × log10(lux)`, one decade per 20 points) is a display-only gauge that compresses the
  30–60 k lx threshold band to 90–96 % and must never drive automation.
- **`firmware/README.md` brought up to v0.6.2** — was still headed *"What this version does
  (v0.4.0)"*, listed `HomeKit.cpp` and `LightSensor.cpp` as stubs, omitted `SolarLogic.cpp` and the
  Solar page entirely, and named the filesystem image per-variant when one `esp32d-littlefs` image is
  shared across variants.
- **`architecture.md` config store corrected** — it described "LittleFS JSON (config + web files) +
  Preferences (calibration values)". All settings live in NVS; LittleFS holds only web assets. That
  split is what lets a filesystem OTA leave every setting intact (ADR 0005).
- **`ai-context.md` refreshed** — file map gained `installation.md`, `user-guide.md`, `pinout.md`,
  `ha-lovelace-card.md`, `ha-card/` and `RELEASE_NOTES.md`; flash figure corrected to 91.3 %
  (`esp32d-pca9685`) from a stale 91.2 %; the HomeKit entry no longer implies pairing works; dropped
  a reference to "v0.4.4", a changelog entry that was never tagged or released.
- **Shutter count is 1–4, not "any number from 1 upward"** (README, ai-context) —
  `Shutters::MAX` is 4; Phase 8 lists raising it to 6 as a prerequisite.
- **`project-brief.md`** now lists all twelve ADRs as decisions of record, not just 0001–0004.
- **`project-plan.md`** records v0.6.1 (selectable sensor bus, ADR 0012) and v0.6.2 (Info hardware
  table, brightness sensor) under Phase 6, and drops a stale note calling Phase 4 hardware-unproven.
- **`.gitignore`** now covers `firmware/dist/` — `*.bin` caught the images but not the card `.js`.

### Release checklist / notes
- **Bins are per-variant from v0.3.0 on** (board × servo backend): a `full` (USB flash) and `ota`
  (firmware) bin **per variant** — `shutter-hub-<variant>-{full,ota}-vX.Y.Z.bin` — plus a **single
  shared `littlefs`** image per version (`shutter-hub-esp32d-littlefs-vX.Y.Z.bin`; the web UI adapts
  to the backend at runtime, so it's identical across variants). Build firmware with
  `pio run -e <variant>` and the FS with `pio run -e <variant> -t buildfs`. Only the active ESP32-D
  variants (`esp32d-direct`, `esp32d-pca9685`) are shipped day-to-day; the C3 variants are deferred.
  **Flash the LittleFS image alongside the firmware** or the device serves the embedded recovery
  page. See [firmware/README.md](firmware/README.md).

## [0.9.2] — 2026-07-12

**Documentation-only — the complete mechanical build package for the tilt actuator.** No firmware
change (stays v0.7.2), no binaries, no GitHub Release. This is the settled, buildable design: the
owner's real slat clip drives a fully hidden rear pull-down linkage through a tape-mounted servo
cradle.

### Added
- **[cad/slat-hook/slat-clip-crank.3mf](cad/slat-hook/slat-clip-crank.3mf)** (P2, produced): the
  owner's Zemismart-style slat sleeve clip, reverse-engineered from the mesh (mouth 8.35 mm wedges
  tight on the measured 8 mm slat — clip fit **confirmed on the real slat**; the 5 mm rod-bar jaw
  is unused), with a solid drill boss added under the bottom strap. Drilled 12 mm from the slat's
  rear edge it gives the rear pull-down crank pin (**26.6 mm @ −16°**). Fitting/drilling notes in
  [cad/slat-hook/README.md](cad/slat-hook/README.md).
- **P1 servo cradle — tape-mount design + drawings** (design doc §7 and
  [docs/diagrams/servo-cradle-p1.svg](docs/diagrams/servo-cradle-p1.svg)): three orthographic
  views. The servo **case** is bonded into the pocket with a second VHB strip — **no screws, the
  mounting tabs are unused** (side walls stop 8 mm short so the tab flange sits proud); plate
  40×34×2.4 VHB'd to the rail's rear face; 4 mm cable gallery with an **open lay-in slot** along
  the long edge so the plug never threads through. 3MF still to be cut on approval.
- **Simulator gains a "v0.9.2 build" preset** (now the default): clip pin 26.6 @ −16°, servo axis
  (+24.7, −49) for the taped stack, M2×35 pushrod at 58 mm, stock 20 mm horn.

### Changed
- **Build baseline finalised.** Measuring the slat at **8 mm / 6 mm** and taping the case (adds a
  second ~1.1 mm layer) sets the servo axis at **(+24.7, −49)** = 10.7 mm off the rail rear face.
  Re-solved: **~132° sweep → 90° slat travel, jam margin 9.3 mm, torque ratio ≤0.77** (≈2.9 kg·cm
  at the slats), rear-most point 44.7 mm from the pivot plane (needs ≥ ~34 mm rail-face-to-glass).
  Everything stays behind the panel; slats close rear-edge-up.

### Notes
- Remaining before printing four sets: the rod pull-force test (≤0.6 kg target) and confirming the
  pivot→staple radius ≈ 36 mm and rail-face-to-glass depth. Feed measurements into the live
  simulator and confirm all flags stay green.

## [0.9.1] — 2026-07-11

**Documentation-only revision of the v0.9.0 mechanical design — no firmware change, no binaries,
no GitHub Release.** The v0.9.0 documentation and simulator presets are retained.

### Changed
- **Hook attachment corrected to the slat's front edge** (owner observation): the drive pin hangs
  at 06:00 (straight down) at closed and sweeps to 03:00 (horizontal, room side) at open — the
  bottom-front quadrant, not v0.9.0's top-rear arc. Closure sense is unchanged (rear edge up at
  closed); the crank phase flips to −180°. New solved baseline (preset "v0.9.1 front-edge hook" in
  the simulator, now the default): hook pin **24 mm on the front-edge line**, stock 20 mm horn,
  **M2×25 pushrod at 46 mm** hole-to-hole (no cutting), servo axis **(+32, −30)** — tucked into the
  corner under the bottom slat, 18 mm behind the rail rear face, still fully **hidden**. ~114°
  servo sweep → 90° slat travel, jam margin 11.3 mm, torque ratio ≤0.85 (≈2.6 kg·cm at slats),
  near-linear mapping. Envelope x ∈ [−24, +39]: rear stays within the tilt rod's own sweep; the
  hook tip sits ~10 mm proud of the panel face at open.

### Added
- **[docs/diagrams/linkage-geometry-front-edge.svg](docs/diagrams/linkage-geometry-front-edge.svg)**
  — solver-generated three-pose drawing of the v0.9.1 layout; now embedded in the README. The
  v0.9.0 drawing `linkage-geometry.svg` is kept.

### Notes
- The v0.9.0 rear/front layouts remain valid only if the hook can place its pin near the rear edge
  (longer under-slat strap, Zemismart-style); both stay available as simulator presets.

## [0.9.0] — 2026-07-11

**Documentation-only version — the mechanical design of the tilt-linkage actuator, settled and
published.** No firmware change (firmware remains v0.7.2), no binaries, and deliberately **no
GitHub Release**; tagged `v0.9.0` purely as a reference point.

### Added
- **[docs/tilt-linkage-design.html](docs/tilt-linkage-design.html)** — self-contained interactive
  design document for the tilt-rod mechanism: exact four-bar solver + animated simulator (enter
  your shutter measurements, scrub the servo, get collision/torque flags, switch mounting presets),
  MG90D mount dimensions, and the 3D-printed parts list (P1 servo cradle, P2 slat-hook crank,
  P3 optional 22 mm arm). Served live via **GitHub Pages** (enabled, `main /docs`):
  <https://rhamblen.github.io/esp32-shutter-hub/tilt-linkage-design.html>.
- **[docs/diagrams/linkage-geometry.svg](docs/diagrams/linkage-geometry.svg)** regenerated from the
  solver: three-pose (closed / mid / open) dimensioned drawing of the rear-mount linkage, replacing
  the superseded twist-rod sketch; embedded in the README again.

### Changed
- **Tilt-rod kinematics corrected** in `docs/project-brief.md` §1 and `cad/README.md`. The original
  10 mm horn : 20 mm arm sizing treated the rod as a venetian-style *twisting* wand (~8 mm travel);
  the plantation hidden tilt rod actually **translates on a 36 mm arc** (~36 mm up + ~36 mm out,
  ~51 mm point-to-point), so the linkage is a genuine four-bar.
- **Baseline linkage design settled after measuring the frame at 28 mm thick** (rules out any
  mortised pocket; the tilt rod sits flush at closed so it cannot be clamped). Both layouts drive a
  printed **slat-hook crank** (26 mm pin) with the stock 20 mm horn: **A (recommended, hidden)** —
  cradle on the bottom rail's *rear* face, axis (+23, −47), 58 mm pushrod, phase −10°, closes rear
  slat edge up; **B (visible)** — room-side face, axis (−21, −41), 52 mm pushrod, phase −170°,
  closes rear edge down. Both: ~122° sweep → 90° slat travel, jam margin ≥10 mm, torque ratio
  ≤0.86 (≈2.6 kg·cm at the slats). Slat hook sits ≥10 mm inboard of the rod's plane so rod and
  pushrod never meet.

### Notes
- Before printing P1/P2, measure: pivot→staple radius (assumed 36 mm), slat pitch (63 mm) and
  thickness, rail-top drop below the bottom pivot (45 mm), rear depth (≥43 mm needed), and the rod
  pull force (target ≤0.6 kg — slacken slat tension screws if over). Feed the numbers into the
  live simulator and confirm all flags stay green.
- Closure direction is tied to the mount side (rear mount closes rear edge up); a flipped servo
  only reverses rotation, absorbed by per-shutter µs endpoint calibration.

## [0.7.2] — 2026-07-10

### Fixed
- **Dashboard/HomeKit tab showed "not paired" when the device was paired.** `HomeKit::paired()`
  returned a transient flag set only by the pairing *event* callback, which doesn't fire at boot for
  pairings already stored in NVS — so after a reboot or an OTA update (pairing survives both) the
  status read false even though Apple Home was still connected. It now derives from the authoritative
  controller list (`controllers() > 0`). Web UI unchanged — firmware-only fix.

### Changed
- **`ServoController::validGpio()` is now chip-aware — closes an ESP32-C3 bricking footgun.** It was a
  hard-coded ESP32-D whitelist; on a C3 it accepted GPIO25/26/27/32/33 (which don't exist) and
  GPIO12–17 (the SPI flash — driving them **bricks boot**). It's now `#if CONFIG_IDF_TARGET_ESP32C3`
  and the C3 build offers only `{0–10, 18–21}`, refusing the flash pins for both the servo signal pin
  and the PCA9685 I²C pins. The C3 is still an untested engineering build (LEDC channel cap, unverified
  hardware), but a servo/I²C pin can no longer be set to a value that bricks the board.

## [0.7.1] — 2026-07-10

Tidy-up of the v0.7.0 HomeKit fix. **No behavioural change** — same fix, cleaned up. The `%m`
HomeSpan patch and the HomeKit health watchdog carry over unchanged.

### Removed
- **All temporary HomeKit investigation diagnostics.** The `[hs]` breadcrumbs threaded through
  HomeSpan's `checkConnect()` (and the `hsCrumb` hook) are gone from `firmware/patches/HomeSpan.cpp`
  and `HomeKit.cpp` — the patch is now the `%m` fix only. The one-shot `[dbg]` bridge summary and the
  `ping` hint are removed.

### Changed
- **Log levels — second pass (completes the v0.7.0 first pass).** Per-action lines moved INFO → DEBUG:
  MQTT cover commands + `rx`, servo attach/detach/test-focus/sweep, HomeKit per-move targets, and the
  solar state-machine's intermediate "counting to trip/clear" / "cancelled" transitions. INFO is now
  reserved for milestones (boot, connections, config/calibration changes, pairing events, the solar
  *action* taken). The HomeSpan status callback is kept as a clean **DEBUG** line (`HomeSpan state: …`).

### Kept from v0.7.0
- The vendored HomeSpan `%m` patch (`firmware/patches/`), the mDNS-on-main-thread init, the HomeKit
  HAP-stall **WARN** watchdog, and `autoPoll` on core 1.

## [0.7.0] — 2026-07-10

**HomeKit pairing works.** The bridge is now discoverable in Apple Home and changes sync both
ways (Home ↔ HA). This is the diagnostic/rollback baseline — it still carries the investigation's
debug logging; v0.7.1 tidies it up.

### Fixed
- **HomeKit was completely undiscoverable and unpairable — root cause found & fixed.** With the bridge
  enabled the device advertised no `_hap._tcp`, the HAP server on port 1201 never opened, and the Home
  app saw nothing. The real cause was **not** mDNS or task/core (both were chased as red herrings):
  HomeSpan 1.9.1's `Span::checkConnect()` validates its mDNS hostname with
  `sscanf(hostName,"%m[A-Za-z0-9-]",&d)`, and **newlib-nano (this arduino-esp32 toolchain) does not
  implement the `%m` allocating conversion**. So `d` was never set, `strlen(hostName)!=strlen(d)` was
  falsely true, and HomeSpan hit its `while(1)` *PROGRAM HALTED* — silently, on the poll task, before
  it ever advertised the service or opened 1201. (`shutter-hub` is a perfectly valid hostname; the
  self-check was broken.)
  - **Fix:** a vendored patch replaces that check with a nano-safe character loop. It lives in
    `firmware/patches/HomeSpan.cpp` and is re-applied to `.pio/libdeps` before every build by
    `patches/apply_patches.py` (`extra_scripts` in `platformio.ini`), so it survives library
    reinstalls and applies to all four variants. See `firmware/patches/README.md`.
- **mDNS now initialised on the main thread** (`WebUI::begin()`, both modes) — hostname + `_http._tcp`;
  HomeSpan adds `_hap._tcp` on top. This replaced the earlier "HomeSpan is sole mDNS owner" scheme,
  which was itself a misdiagnosis of the `%m` hang.

### Added
- **HomeKit health watchdog (WARN).** `HomeKit::loop()` now logs a `WARN` if HomeSpan's connect
  callback hasn't fired within 10 s of boot — i.e. the bridge is stalled, not discoverable, 1201 closed.
  Previously it failed silently.
- **HomeKit diagnostics (temporary, removed in v0.7.1).** HomeSpan `setStatusCallback` streamed to the
  web **Logs** page; a one-shot bridge summary (`running/paired/controllers/hapUp/host/freeHeap`); and
  `[hs]` breadcrumbs threaded through HomeSpan's `checkConnect()` that pinpointed the `%m` hang.

### Changed
- **Log levels — first pass.** MQTT publish (`tx …`) traffic moved to **VERBOSE** (a failed publish now
  logs **WARN**); MQTT `subscribed …` lines and the HomeKit `[dbg]` lines moved to **DEBUG**, so INFO
  reads as a clean operational narrative. (Full Servo/Solar reclassification lands in v0.7.1.)
- **HomeSpan poll task** now runs on **core 1** (`autoPoll(16384,1,1)`), changed from core 0 while
  diagnosing; core was not the cause, but core 1 is tested-good and left as-is.

### Notes
- No behavioural change to servos, MQTT/HA control, or the solar logic. All four variants
  (`esp32d-{direct,pca9685}`, `esp32c3-{direct,pca9685}`) build with the fix; the C3 bins remain
  untested engineering builds.

## [0.6.2] — 2026-07-10

**Check the wiring from the Info page.** A hardware table naming every device, its bus, its pins and
its channel — plus HomeKit status alongside MQTT. And a human-readable brightness percentage next to
the raw lux reading.

### Added
- **Hardware & wiring table** on the **Info** page — one row per physical device, so the pinout on
  screen can be read straight off against the board:
  - **PCA9685 builds** — the driver's I²C bus (and whether the VEML7700 is **sharing** it or it's
    **servos only**), its SDA/SCL GPIOs, address `0x40`, and whether it's driving or released.
    Beneath it, one indented row per shutter giving its **channel** and calibration state.
  - **Direct-GPIO builds** — the servo's signal GPIO and an explicit *"no channel — single servo"*;
    no channel rows are drawn, because there is nothing to check.
  - **VEML7700** — dedicated (`Wire1`) or shared with the PCA9685 (`Wire`), the SDA/SCL GPIOs
    actually in use (the PCA9685's, when shared), address `0x10`, and detected / not detected /
    disabled. A footnote calls out a one-controller chip, a sensor not ACKing, and the fact that the
    servo bus pins are set on the Servo-test page.
- **HomeKit status on the Info page** — `Disabled` · `Enabled — reboot to start` ·
  `Active — not paired` · `Paired — N controller(s)`, matching the System ▸ HomeKit tab.
- **Brightness sensor (0–100 %)** — a human-facing companion to the raw lux reading, published
  retained on `<base>/solar/brightness` and discovered in Home Assistant as **Brightness** (`%`,
  `mdi:brightness-percent`). Also shown on the web UI's Solar ▸ Status card and exposed on
  `/api/solar` as `sensor.brightness`.
  - **Logarithmic, one lux decade per 20 points** — `20 × log10(clamp(lux, 1, 100000))`. Anchors:
    1 lx → 0 %, 10 → 20, 100 → 40, 1 k → 60, 10 k → 80, 100 k → 100. A dark room reads 0 %, a lit
    room 40 %, a bright room 54 %, overcast daylight 80 %, full sun 100 %.
  - A **linear** percent of the 120 k lx full scale was rejected: it reads 0 % for every indoor
    level and only starts moving in direct sun.

### Notes
- **Brightness is display-only.** The solar state machine still trips on **raw lux**. The log curve
  deliberately compresses the 30–60 k lx band the thresholds live in (clear = 90 %, trip = 96 %), and
  it isn't cleanly invertible — never drive automation from it. Raw `lux` keeps publishing unchanged,
  which is also what Phase 8b's HA-history calibration reads.
- The existing solar entities are **unchanged**: the `Solar automation` switch and the two writable
  lux threshold `number`s remain published to Home Assistant, and the Lovelace card keeps its
  solar toggle.
- **The sensor's low end is coarse by design.** At gain 1/8 one count is ~1.84 lx (≈ 5 % on this
  curve), so a dark room reads 0 % and the first step is visible. That's the price of a full scale
  that reaches direct sunlight.
- **The Info page is a mirror, not a control.** Every value in the hardware table is set elsewhere —
  servo bus pins on **Servo test**, channels on **Shutters**, the sensor bus on **Solar**. It exists
  so all three can be checked against the board in one place.

### Changed
- `GET /api/info` gained four objects: `servo` (`usesPca`, `pin`, `channel`, `sda`, `scl`,
  `attached`), `sensor` (`enabled`, `present`, `bus`, `sda`, `scl`, `dedicatedSupported` — the pins
  are the **active** ones, after any clamp to the shared bus), `homekit` (`enabled`, `running`,
  `paired`, `controllers`), and `shutters` (`name`, `channel`, `calibrated` per blind).
- `ha-card/shutter-hub-card.js` — `CARD_VERSION` stamped `0.6.2` (rides the project SemVer stream;
  no functional change to the card).

## [0.6.1] — 2026-07-10

**The sensor's I²C bus is now a setting** — and with it, solar heat protection works on the ESP32-C3.
Plus the full installation and user guides, and a pinout reference.

### Added
- **Selectable sensor bus** ([ADR 0012](docs/decisions/0012-selectable-sensor-i2c-bus.md)) — the
  VEML7700 can sit on its **own `Wire1`** (default, SDA 25 / SCL 26 — the fault-isolated choice from
  ADR 0011) **or share the PCA9685's `Wire`** (GPIO21/22). Chosen on the **Solar** page. A dedicated
  bus needs a second I²C controller, so on a one-controller chip the preference is **clamped to
  shared** and the dedicated option is disabled with an explanation.
- **[docs/installation.md](docs/installation.md)** — end-to-end install guide: USB first flash,
  captive-portal WiFi setup, servo smoke test, per-shutter calibration, MQTT/Home Assistant,
  the Lovelace card, HomeKit pairing, solar thresholds, web auth, and OTA updates. Each step
  carries its own troubleshooting table.
- **[docs/user-guide.md](docs/user-guide.md)** — everyday operation: the four saved positions,
  the four control faces (web UI, HA, Apple Home, Lovelace card), solar behaviour incl. hysteresis
  and the 2 h manual override, recalibration, and routine maintenance. Embeds the Shutters and Solar
  page mockups, footnoted as mockups rather than captures.
- **[docs/pinout.md](docs/pinout.md)** — GPIO map for both boards: the ESP32-D defaults the firmware
  actually ships, the pins `validGpio()` rejects and why, and a **proposed** ESP32-C3 map.

### Fixed
- **Solar failed silently on the ESP32-C3.** The C3 has one I²C controller (`SOC_I2C_NUM == 1`) to
  the ESP32-D's two, but the Arduino core declares `Wire1` unconditionally — so the C3 build linked
  cleanly and then `Wire1.begin()` returned `ESP_ERR_INVALID_ARG` at runtime. The sensor reported
  *"not detected"* forever, with nothing to distinguish it from a wiring fault. The bus setting above
  fixes this: the C3 falls back to the shared bus and the sensor works.
- **GPIO34–39 could be saved as dedicated I²C pins.** They're input-only and can never drive an
  open-drain I²C line. `POST /api/solar` now validates dedicated-bus pins with
  `ServoController::validGpio()` (correct here — dedicated mode only exists on the ESP32-D) and
  rejects identical, non-output-capable, or strapping pins.
- **Stale "shared I2C bus" notes**, which contradicted [ADR 0011](docs/decisions/0011-dedicated-sensor-i2c-bus.md)
  and the shipped v0.6.0 firmware. `project-brief.md` claimed "PCA9685 and VEML7700 share one bus"
  and omitted the sensor bus from its pinout table; `architecture.md` still gave "shared I2C with
  sensor" as a reason to pick the PCA9685; `project-plan.md` D9 referred to "the shared I2C bus".

### Changed
- **README** — new **Installation** section (five-step summary linking to the guides above); the
  hardware table now carries default pins per component; new documents listed in the repo-layout table.
- `AppConfig::setLightSensor()` takes a `bus` argument; new `lsBus()` / `SensorBus` enum in NVS.
  `LightSensor` gained `dedicatedSupported()`, `activeBus()`, `activeSda()`, `activeScl()`, and
  `/api/solar` reports all four so the (variant-shared) web UI can adapt at runtime.

### Notes
- **`reconfigure()` never tears down a shared bus.** `TwoWire::end()` really does deinit the
  peripheral — calling it on `Wire` would kill the PCA9685 and freeze every servo. Only the dedicated
  `Wire1` is ever ended. Conversely `TwoWire::begin()` **is** idempotent on an already-started master
  bus, which is why shared mode needs no ownership handshake with `ServoController`.
- **Shared mode re-couples sensor and servos** — a shorted sensor lead can wedge the servo bus. It is
  opt-in, off by default on the ESP32-D, and the UI says so. ADR 0011's reasoning is unchanged; it is
  now the default rather than the only mode.
- **The ESP32-C3 is still not shippable**, and no C3 binaries are attached to releases. This release
  removes the *solar* blocker; `validGpio()` still carries the ESP32-D whitelist and would accept
  pins that don't exist on a C3 (25/26/27/32/33) or that are its SPI flash (12–17). See
  [docs/pinout.md](docs/pinout.md).
- Flash: **91.3 %** (`esp32d-pca9685`), 91.9 % (`esp32d-direct`); C3 envs link at 89.5 % / 90.1 %.

## [0.6.0] — 2026-07-10

**Phase 6 — light sensor + solar heat protection.** The hub now watches the sun and moves the
shutters before the room bakes. A **VEML7700** ambient-light sensor feeds a trip/clear state
machine with dwell timers; the whole feature is configurable from a new **Solar** page, exposed to
Home Assistant over MQTT, and surfaced on the Lovelace card. It can be built, driven and tested
**before the sensor physically exists** via a simulate-lux slider.

### Added
- **`LightSensor`** — real VEML7700 driver (was a stub) on its **own I²C bus, `Wire1`**, pins
  configurable (default **SDA 25 / SCL 26**). Lean vendored register driver, no new library
  dependencies. Fixed gain 1/8 + 25 ms integration → full scale ≈ 120 k lx.
- **`SolarLogic`** — `idle → counting-trip → tripped → counting-clear → idle` state machine.
  Trips when lux stays **above** the trip threshold for its dwell; clears when it stays **below**
  the clear threshold for its dwell. The gap between the two is the hysteresis that stops passing
  clouds flapping the shutters.
- **Five-option actions.** The bright and clear targets are each one of **Open · Closed ·
  Daylight · Privacy · Do nothing**. `Do nothing` advances the state but drives no servos — so the
  default clear leaves the slats where the trip put them, and setting *both* to `Do nothing` makes
  the hub a pure sensor/reporter.
- **Manual override.** A user move on a shutter (web recall, or an MQTT `set` / `position/set` /
  jog / recall from Home Assistant) suspends solar automation **on that shutter for 2 hours**. The
  hub-wide state still tracks the light; suspended shutters are simply skipped when an action fires.
- **Solar page** in the web UI — Status (live lux, state, countdown, **simulate-lux slider** +
  "Use live sensor"), Sensor (type, Wire1 pins, live `detected @0x10` pill, enable), Sensitivity
  (four numbers: trip lux/dwell, clear lux/dwell), Actions (the two target selectors + automation
  switch). New `/api/solar` (GET/POST) and `/api/solar/simulate` routes.
- **MQTT / Home Assistant** — new hub-wide entities via discovery: an **illuminance sensor**
  (`<base>/solar/lux`), a **solar state sensor**, a **`Solar automation` switch**, and two writable
  **`number`** entities for the trip and clear lux thresholds. The two numbers are the write-back
  hook a future HA-side calibration card will use. Threshold writes that would put clear ≥ trip are
  rejected (inverted hysteresis oscillates). Topics documented on the MQTT ▸ Topics tab.
- **`shutter-hub-card` v0.6.0** — optional solar toggle + live lux caption in the group header,
  driven by three **optional** config keys (`solar_switch`, `solar_lux`, `solar_state`). Omit them
  and the card renders exactly as before, so no-sensor installs are unaffected.

### Changed
- **The light sensor no longer shares the PCA9685 I²C bus** — see
  [ADR 0011](docs/decisions/0011-dedicated-sensor-i2c-bus.md), which supersedes the "one shared
  bus, no clash" line in `architecture.md` / `ai-context.md`. A shorted sensor lead can no longer
  wedge the servo driver.
- `AppConfig` gained the sensor (enable/type/SDA/SCL) and solar (enable, thresholds, dwells, both
  targets) settings; all persist in NVS and are covered by **Reset config**.

### Notes
- **Reported lux is approximate.** The driver reports the linear `counts × resolution`; the Vishay
  high-lux correction polynomial is deliberately skipped because it diverges across the 60–120 k lx
  band the sensor exists to watch. Thresholds are calibrated against what *this* sensor reports —
  which is exactly what the planned HA-history calibration does anyway. Rationale in ADR 0011.
- **Solar config applies without a reboot** (unlike HomeKit) — saving re-inits the bus in place.
- Flash use is now **91.2%** on `esp32d-pca9685`. The lean driver choice was load-bearing: the
  Adafruit VEML7700 library (plus BusIO + Unified Sensor) would very likely not have fit.

## [0.5.4] — 2026-07-09

**HomeKit discovery, take 2 — single mDNS owner.** The Home app still couldn't discover the bridge
after v0.5.2. Comparing against the proven-good **HomeKey-ESP32** (which also runs HomeSpan + a web
server + MQTT) showed the real difference: *its web server never touches mDNS — HomeSpan is the sole
owner.* Ours had two initialisers of the one shared ESPmDNS responder (WebUI's `_http` + HomeSpan's
`_hap`), which left `_hap._tcp` unannounced.

### Fixed
- **WebUI no longer calls `MDNS.begin()` when HomeKit is enabled** — it defers to HomeSpan, which
  becomes the sole mDNS owner (same hostname via `setHostNameSuffix("")`, so `<name>.local` still
  resolves; `HomeKit::begin()` re-adds the `_http` service under HomeSpan's responder). When HomeKit
  is disabled, WebUI owns mDNS exactly as before. Removed the v0.5.2 `MDNS.end()` band-aid (there's
  now nothing to tear down — only one initialiser runs).

### Notes
- Confirmed the network is fine: other HomeKit accessories pair normally on the same 5 GHz phone, so
  the fault was our advertisement, not the WiFi. This is the fix for "iPhone finds nothing".

## [0.5.3] — 2026-07-09

**HomeKit no longer freezes the servos.** With the bridge enabled, servo control (both the Servo-test
page and Home Assistant/MQTT) stopped working; disabling HomeKit restored it — confirmed by A/B test
against v0.4.1 and against v0.5.1 with HomeKit off.

### Fixed
- **`homeSpan.poll()` was starving the main loop.** It was called from the Arduino `loop()`, sharing
  the single cooperative loop with `ServoController::loop()` (which writes each slewed servo frame to
  the PCA9685) and `Mqtt::loop()`. HAP handling — especially the SRP pairing crypto — holds the CPU
  long enough that servo frames and MQTT commands were never serviced, so shutters didn't move and HA
  control went dead while the bridge ran. HomeSpan now runs on its **own FreeRTOS task**
  (`homeSpan.autoPoll(16384, 1, 0)` — 16 KB stack for the SRP math, core 0 alongside WiFi/AsyncTCP),
  leaving the main loop (core 1) free to slew servos and pump MQTT regardless of HAP activity.
  `HomeKit::loop()` no longer calls `poll()` — it only services the deferred pairing reset.

### Notes
- This is independent of the HomeKit **pairing/discovery** issue (that's network/mDNS — the iPhone
  must be on the same L2 network as the hub). v0.5.3 makes the hub *usable* with HomeKit enabled;
  discovery still requires the phone and hub to share a network segment.

## [0.5.2] — 2026-07-09

**HomeKit discovery fix.** On hardware the bridge ran and logged the right pairing code, but the
iPhone never found it in *Add Accessory* — so pairing (QR or manual) had nothing to attach to.

### Fixed
- **`_hap._tcp` mDNS service was never announced** because the web UI had already called
  `MDNS.begin()`; HomeSpan's own `MDNS.begin()` then no-ops on the already-running responder and the
  HAP service came out unannounced. `HomeKit::begin()` now calls `MDNS.end()` right before
  `homeSpan.begin()` so HomeSpan gets a clean mDNS init and advertises `_hap._tcp` properly; the web
  UI's `_http` service is re-added immediately after (so `<name>.local` keeps working). This is the
  fix for "iPhone finds nothing to pair with".

## [0.5.1] — 2026-07-09

**Reliable reboot.** Field-testing v0.5.0 exposed that the device often wouldn't restart on command
— OTA firmware flashes and the web *Reboot* buttons set a flag serviced by the Arduino `loop()`, and
when the loop is starved/blocked the restart never fired (so a freshly-flashed image never ran until a
physical power-cycle). Reboots now fire from a high-priority `esp_timer`, independent of `loop()`.
New firmware + filesystem bins.

### Fixed
- **`Diagnostics::scheduleReboot()`** — restarts via a one-shot `esp_timer` (dispatched on the
  high-priority timer task), so a reboot happens even if `loop()` is stalled. `/api/system/reboot`,
  *Reset WiFi*, and *Reset config* now send their response, do their NVS work inline, then schedule
  the restart — no more loop-serviced `pending*` flags.
- **OTA no longer auto-reboots**, removing a race: flashing firmware *then* filesystem could fire the
  restart mid-filesystem-write or lose it entirely. Flash firmware and/or filesystem in any order,
  then click **Reboot** (now reliable). The OTA page highlights *Reboot* after any flash.

### Changed
- `WiFiSetup::forget()` added (clear WiFi creds without restarting); `forgetAndReboot()` builds on it.

### Migration
- To get onto v0.5.1: OTA-flash the `…-ota-v0.5.1.bin` firmware (+ `…-littlefs-v0.5.1.bin`), then
  **power-cycle once** to activate it (v0.5.0's software reboot is the very thing being fixed, so it
  can't be relied on for this last hop). From v0.5.1 onward, the *Reboot* button is dependable.

## [0.5.0] — 2026-07-09

**Phase 5 — Apple HomeKit.** The HomeSpan bridge behind the config tab shipped in v0.4.4 is now
live: each configured shutter appears in Apple Home as a **Window Covering**, pairable directly
(no hub) and controllable alongside Home Assistant. New firmware **and** filesystem bins.

### Added
- **HomeSpan bridge** ([firmware/src/HomeKit.cpp](firmware/src/HomeKit.cpp)) — one HAP *Window
  Covering* accessory per shutter under a single bridge. `update()` drives the same
  `ServoController` slot as MQTT; `loop()` streams the live position back and, once the servo
  settles, syncs Apple Home's target to the real position so moves made elsewhere (MQTT, the web
  UI) are reflected in Home too. Position maths mirror the MQTT cover exactly (0 % = closed unless
  the shutter's scale is inverted); an uncalibrated shutter rejects target changes.
- **`homespan/HomeSpan @ ~1.9.1`** dependency — pinned to the 1.9.x line, the last that supports
  arduino-esp32 core 2.0.9 (HomeSpan 2.x requires core ≥ 3.3.0; upgrading the core would churn
  every other library, so it stays on 2.0.9).
- **Live bridge state** — `/api/homekit` now reports real `running`/`paired`/`controllers`; the
  System ▸ HomeKit tab shows *Running* / *Enabled — reboot to start* / *Disabled*, enables
  *Reset pairings* only when the bridge is up, and its pairing QR is now the real, scannable code.
- **Operable-by-default shutters (MVP)** — HomeKit is for *driving* blinds, not configuring them, so
  an uncalibrated shutter is now still operable in Apple Home: it falls back to the servo's pulse
  envelope (min = closed, max = open) for a usable 0–100 % range. Calibrate in the web UI for
  accurate travel; the accessory logs which mode it's in.
- **Active pairing code echoed to the web Logs page** at start-up (HomeSpan's own pairing log only
  reaches the USB serial console) — so the code the *running* bridge expects can be checked against
  what the tab shows.

### Fixed
- **Pairing failed after changing the setup code (“code not recognised” / QR hangs).** The pairing
  verifier is baked in at boot, so a code (or enable, or bridge-name) changed in the web UI never
  reached the running bridge until a restart — leaving the tab showing one code while the device
  paired against another. The HomeKit tab now has an explicit **Reboot to apply** button; *Save*
  no longer implies “applied”, and directs you to reboot before pairing.

### Changed
- **`HomeKit::loop()`** added to the main loop (pumps `homeSpan.poll()` + the deferred pairing
  reset). *Reset pairings* erases HomeKit pairing data and reboots (HomeSpan `'H'`), deferred ~400 ms
  so the HTTP response flushes first.
- HomeKit tab copy updated now the bridge is real (no longer "arrives with v0.5.0"); notes that
  enabling, or adding/removing shutters, takes effect after a reboot.

### Design decisions / coexistence
- **Port 1201 for HAP** (`setPortNum`) — the async web server keeps port 80.
- **mDNS hostname pinned to the device name** (`setHostNameSuffix("")`) so `<name>.local` still
  resolves the web UI; HomeSpan re-runs `MDNS.begin()`, so the `_http` service is re-asserted after.
- **WiFi stays with WiFiManager** — we're already connected before HomeSpan polls, so its
  `checkConnect()` sees `WL_CONNECTED` and never calls `WiFi.begin()` itself (no startup blip); it's
  handed the live creds only for its own later reconnects.
- **QR setup ID `SHUT`**, category *Bridges* (2), protocol IP (2) — the web UI's `X-HM://` payload
  is computed to match HomeSpan's own encoder byte-for-byte.
- **Flash is now ~90 %** of the 1.3 MB app partition (was ~63 %) — HomeSpan pulls in the HAP/SRP
  crypto. Still fits with OTA headroom, but Phase 6 (light sensor) must budget against the remaining
  ~10 %.

### Known limitations
- The accessory tree is built once at boot, so **any HomeKit change — enable, setup code, bridge
  name, adding/removing a shutter — needs a reboot** to take effect (MQTT still updates live). The
  tab now surfaces this with a *Reboot to apply* button.
- Pairing itself is confirmed on real hardware with an Apple device: save → *Reboot to apply* →
  scan the QR or enter the code shown. The active code is echoed to the web Logs page to cross-check.

## [0.4.4] — 2026-07-09

HomeKit **configuration tab** (Phase 5 groundwork) — the System ▸ HomeKit sub-tab now stores the
bridge settings, ahead of the HomeSpan bridge itself (v0.5.0). Same pattern as the MQTT tab, which
shipped its config before the Phase 4 integration. New firmware **and** filesystem bins.

### Added
- **System ▸ HomeKit sub-tab** — enable toggle, **bridge name** (defaults to the device name) and
  **setup code** (8 digits, shown as `XXX-XX-XXX`, with a *Random code* generator), bridge/pairing
  status rows, a disabled *Reset pairings* button (live once the bridge runs), and a **pairing QR
  code** (`X-HM://` payload, category *bridge*, setup ID `SHUT`) rendered client-side via
  `qrcode.min.js` (qrcodejs 1.0.0, MIT, added to the LittleFS bundle).
- **Default setup code `748-88-377`** — "SHUTTERS" on a phone keypad; deliberately distinct from
  HomeSpan's own default `466-37-726` ("HOMESPAN" by the same trick).
- **`/api/homekit` GET/POST + `/api/homekit/reset-pairings`** — config persisted to NVS
  (`AppConfig::hkEnabled/hkBridgeName/hkSetupCode`); the setup code is validated device-side
  against Apple's banned trivial codes (all-same digits, `12345678`, `87654321`). Reset-pairings
  returns 409 until the bridge exists.
- **[HomeKit.h](firmware/include/HomeKit.h) stub API** — `running()/paired()/controllers()/resetPairings()`,
  so Phase 5 only swaps the module's internals. Contract noted there: QR setup ID `SHUT`
  (`homeSpan.setQRID`), HAP off port 80 (`homeSpan.setPort(1201)`), WiFi stays with WiFiManager.
- **Icons on the tab bars** — inline `currentColor` SVGs on both sub-tab rows: System ▸ cog
  (Device), wifi arcs (WiFi), house (HomeKit), shield (Security); MQTT ▸ globe (Broker), inbox
  (Topics). On phones the icon'd tabs collapse to icon-only. (SSL/TLS was considered and
  deliberately left out — the broker is local-LAN Mosquitto, so plaintext MQTT is the norm and
  on-device TLS isn't worth the cert-management and handshake-RAM cost.)

### Changed
- Factory reset (`Reset config`) now also clears the HomeKit settings; confirm text updated.

## [0.4.3] — 2026-07-09

Card-only patch. Frontend only — **no firmware change**, so no new firmware/filesystem bins.

### Changed
- **`shutter-hub-card` button order** is now **Close · Privacy · Daylight · Open** (was
  Open · Close · Daylight · Privacy) — a closed→open progression. The deployed inline resource on
  *My Home › Shutters* was updated in place (hard-refresh to pick it up).

## [0.4.2] — 2026-07-09

Home Assistant **operating card** (Phase 4b, first cut) — a custom Lovelace card for the shutters.
Frontend only: **no firmware change**, so no new firmware/filesystem bins ship with this release.

### Added
- **`shutter-hub-card` — Lovelace operating tile** ([ha-card/shutter-hub-card.js](ha-card/shutter-hub-card.js)):
  1–6 named shutters side by side, each with a slat glyph that tracks position. The four blind states —
  **Open · Close · Daylight · Privacy** — plus a **manual position slider** (arbitrary 0–100 %) and a
  **Stop**, applied to **all shutters at once** or to **one selected shutter** (tap a tile to scope,
  *Select all* to return). Binds to the ADR-0005 discovery entities (`cover.<hub>_<id>` +
  `button.<hub>_<id>_daylight`/`_privacy`, the button ids auto-derived from the cover id). Plain custom
  element, no build step; themes off HA CSS variables. New [ADR-0007](docs/decisions/0007-ha-lovelace-card.md)
  and build spec [docs/ha-lovelace-card.md](docs/ha-lovelace-card.md).
- **Deployed to Home Assistant** — registered as an inline `module` dashboard resource and added as a
  new **Shutters** view on the **My Home** dashboard (both currently-configured shutters). Movable later.

### Notes
- **Calibration / config card is deferred**, on purpose: raw-µs set-and-go, the full-open/close travel
  endpoints, and *saving* into the four slots need firmware commands that don't exist yet (`goto_us`,
  raw-µs readback, `save:open`/`save:close`). Specified for a future phase in
  [docs/ha-lovelace-card.md](docs/ha-lovelace-card.md) §4; until then, calibrate in the hub web UI.
- The card caps at 6 shutters; the firmware still defines `Shutters::MAX = 4` — raising it to 6 is
  part of the deferred calibration-phase work.

## [0.4.1] — 2026-07-09

### Changed
- **Declared icons on the per-shutter HA buttons** — the MQTT discovery payloads now set each
  button's icon device-side, so the entities look right everywhere in HA (device page,
  auto-dashboards, pickers): **Daylight / Privacy recall** → `mdi:window-shutter-settings`,
  **Jog open / close** → `mdi:chevron-double-up` / `mdi:chevron-double-down`,
  **Save daylight / privacy** → `mdi:content-save-cog`. Retained configs republish on connect —
  entities update in place, nothing to redo in HA. The cover keeps its `device_class: shutter`
  state-driven icon.

## [0.4.0] — 2026-07-09

MQTT / Home Assistant cover control (Phase 4): every configured shutter becomes a native HA
`cover` plus six `button` entities via MQTT discovery, driving real servo channels — several at
once. Implements the [ADR-0005](docs/decisions/0005-mqtt-command-structure.md) command table
(the Phase-4b calibration-card commands — `goto_us`, `save:open`/`save:close`, raw-µs readback —
stay deferred to that phase).

### Added
- **Per-shutter MQTT cover control** — the hub subscribes to
  `<base>/cover/<id>/set` (`OPEN` | `CLOSE` | `STOP`), `<base>/cover/<id>/position/set` (`0–100`)
  and `<base>/cover/<id>/cmd` (`jog_open` | `jog_close` | `recall:daylight` | `recall:privacy` |
  `save:daylight` | `save:privacy`), wired to each shutter's calibrated endpoints/favourites and
  its own PCA9685 channel. Jog steps **25 µs** per press, clamped to the calibrated travel.
  `OPEN`/`CLOSE`/position commands on an **uncalibrated** shutter are ignored with a logged
  warning (jog and save still work).
- **Per-shutter state publishing** — `<base>/cover/<id>/position` (`0–100`) and
  `<base>/cover/<id>/state` (`opening|closing|open|closed|stopped`), both **retained**, published
  on change (≤4 Hz while moving). Position honours the per-shutter **Invert** scale; an
  uncalibrated shutter reports `0`/`closed` per the assembly-home convention
  ([ADR-0009](docs/decisions/0009-servo-position-memory.md)). Moves made from the web UI are
  reflected too — HA always tracks the real position.
- **Home Assistant discovery per shutter** — one `cover` (device class `shutter`, position +
  set-position + state + availability) and six `button` entities (Jog open/close,
  Daylight/Privacy recall, Save daylight/privacy — the save pair marked `entity_category:
  config`), all grouped under the hub device and sharing the hub's `<base>/status` LWT.
  Discovery **re-publishes automatically** when a shutter is added / removed / renamed /
  re-channelled / inverted / recalibrated — a deleted shutter's entities and retained state are
  removed from the broker (no reconnect needed).
- **Concurrent per-channel servo drive** ([ADR-0010](docs/decisions/0010-concurrent-servo-drive.md))
  — `ServoController` now keeps independent slew state per output ("slot"): every commanded
  channel moves simultaneously at the shared speed limit, so an HA "close all" really closes all.
  New slot API (`moveSlotUs`, `stopSlot`, `slotUs`, `slotTargetUs`, `slotMoving`); per-slot
  position memory in NVS (extends ADR-0009). Direct-GPIO builds are unchanged (one slot).
- **MQTT page — live Topics map** — the read-only Topics sub-tab now lists the real topics for
  every configured shutter (command / position-target / custom / position / state, with payload
  hints and direction badges), updating live as the base topic is edited, plus the hub-wide rows
  and a discovery-prefix note.

### Changed
- **Servo-test channel switching no longer freezes an in-flight move** — with per-slot state,
  changing the test focus lets the old channel finish its slew (previously it was abandoned
  mid-travel). Detach still releases only the active channel.
- **Shutters page channel hint** updated: on a PCA9685 build the per-shutter channel now routes
  MQTT/HA cover commands directly.

### Notes
- **Simultaneous peak current is now real** — ~3–4 A with four MG90Ds moving at once, which the
  XL4015 rail was sized for ([ADR-0003](docs/decisions/0003-power-chain-xl4015-pca9685.md)). On a
  USB-powered bench rig, avoid multi-shutter scenes. Soft-start staggering is deferred (ADR-0010).
- Uses wildcard subscriptions (`<base>/cover/+/…`), so no re-subscribe is needed when shutters
  change; discovery/state refresh is deferred to the MQTT task loop for thread safety.

## [0.3.0] — 2026-07-08

Build variants and a real PCA9685 servo backend. The servo hardware is now a compile-time choice,
identified everywhere so an OTA bin is never ambiguous.

### Added
- **Build variants — board × servo backend** — the servo driver is a compile-time choice,
  `-D USE_PCA9685=0|1`: **direct GPIO** (ESP32Servo, one bench actuator) or **PCA9685** (Adafruit PWM
  driver, I2C multi-channel — the production topology from [ADR-0003](docs/decisions/0003-power-chain-xl4015-pca9685.md)).
  Four PlatformIO envs — `esp32d-` / `esp32c3-` × `-direct` / `-pca9685` — each carrying an
  `FW_VARIANT` id; only the ESP32-D pair is active, **`esp32d-pca9685` is the default**, and the C3
  envs stay deferred. New [ADR-0008](docs/decisions/0008-build-variants.md).
- **Variant identity on-device** — `GET /api/info` gains `variant` (e.g. `esp32d-pca9685`) and
  `backend` (`gpio`|`pca9685`); both show on the **Dashboard** Device card and the **OTA** page, and
  name the release artifacts `shutter-hub-<variant>-{full,ota,littlefs}-vX.Y.Z.bin`.
- **PCA9685 servo backend** — on a `-pca9685` build, `ServoController` drives the servo through a
  PCA9685 at `0x40` over I2C (Adafruit PWM Servo Driver, 50 Hz, `writeMicroseconds`), releasing the
  channel (full-OFF) on detach. The µs position core (slew/speed/sweep) is shared with the direct
  build — only the hardware primitives switch.
- **Adaptive Servo-test page** — the one page renders the right controls for the running backend
  (from `/api/info`): the **direct** build keeps the signal-GPIO selector; the **PCA9685** build gets
  **I2C SDA/SCL pin selectors** and a **servo-channel (0–15) selector**. New config in `AppConfig`
  (`i2cSda`/`i2cScl` default 21/22, `servoChannel` default 0) and REST `POST /api/servo/channel`,
  `POST /api/servo/i2c`.

### Changed
- **`platformio.ini` restructured** into the four variant envs with backend mixins;
  `default_envs = esp32d-pca9685`. Added `adafruit/Adafruit PWM Servo Driver Library` to `lib_deps`
  (only linked on `-pca9685` builds).
- **Releases ship per-variant firmware** (`full` + `ota`) plus a **single shared LittleFS** image
  per version (the UI adapts at runtime, so the FS bin is variant-independent).
- `FW_VERSION` → **0.3.0**.

### Added
- **Servo position memory + "home" convention** ([ADR-0009](docs/decisions/0009-servo-position-memory.md)) —
  tackles the open-loop first-move jump (an unfed servo has no position, so its first pulse snaps the
  arm at full speed). `ServoController` now persists each drive slot's last position to NVS
  (`AppConfig::servoPos`/`setServoPos`, keys `svp0..svp15`; direct = slot 0, PCA9685 = channel) and
  restores it on boot, so a **warm reboot / OTA** (servos still powered) restores where the arm is and
  the first move slews from there — no snap. Writes are **debounced** (~3 s after a move settles, plus
  on detach and channel switch) to spare the flash. A never-driven channel defaults to **`HOME_US`**
  (the minimum-µs "closed" endpoint); fit the horn parked there at assembly (see
  [hardware-layout.md](docs/hardware-layout.md)) so a factory-fresh first boot also matches reality.

### Fixed
- **Channel switch no longer jolts the servo** — on a PCA9685 build, selecting a channel used to
  drive the *new* channel to the *previous* channel's pulse width at full speed (and release the old
  channel). Each channel now keeps its own remembered position, and switching focus **moves and
  releases nothing** — essential once a channel is a live blind. Actual moves still slew at the set
  speed.
- **Shutter calibration now drives the selected shutter's channel** — it was driving whichever
  channel the Servo-test page last left active, so every shutter appeared to move the one servo.
  Selecting a shutter (or reassigning its channel) now points the driver at that shutter's PCA9685
  channel first.

## [0.2.2] — 2026-07-08

Per-blind calibration (Phase 2): a dedicated Shutters page, microsecond-native servo control, and a
stale-web-UI cache fix.

### Added
- **Shutters page — per-blind calibration (Phase 2, in progress)** — a new **Shutters** sidebar page,
  separate from the low-level **Servo test** diagnostic (the old *Actions* tab, renamed). Define
  shutters (friendly name, PCA9685 channel — declared but not yet wired), then calibrate each in the
  browser: a **µs scrubber** plus a video-editor-style **transport cluster** (slow-run → **Stop** →
  frame-step **nudge**, Fine 5 µs / Coarse 25 µs). A single **Positions** panel holds all four targets —
  **Full open, Full close, Daylight, Privacy** — each with the same **Save current** (snapshot the live
  position) and **Go** (recall, disabled until set) controls, so open/close are managed exactly like the
  favourites. The **slider ends are labelled OPEN / CLOSED** with their pulse widths, and **swap when
  Invert is on**, so travel direction is always explicit and can't be reversed by accident. Position shown as
  both pulse width and derived **% of travel**. A per-shutter **Invert position scale** setup toggle
  flips the readout to **0 % = open** (default is **0 % = closed**, the Home Assistant standard). New
  `Shutters` module persists definitions + calibration in their **own NVS namespace** (survives a
  filesystem OTA *and* a config reset), per [ADR-0005](docs/decisions/0005-mqtt-command-structure.md).
- **UI mockup** — [docs/diagrams/calibration-page.svg](docs/diagrams/calibration-page.svg), a
  dark-theme wireframe of the Shutters page, linked from the Phase 2 plan.

### Fixed
- **Stale web UI after reflashing** — `serveStatic` on LittleFS sent no `Cache-Control`, and LittleFS
  files report an epoch `Last-Modified`, so browsers could cache `index.html`/`app.js`/`style.css`
  indefinitely. After flashing a new filesystem image the browser could keep running the *old* JS
  (old button wiring/ids) until a hard refresh — e.g. **Go** on Full open/close appearing to jump to
  the wrong saved position because stale JS was still bound to old element IDs. Static assets are now
  served with `Cache-Control: no-cache`, so the browser always revalidates. **If you've hit this,**
  do one hard refresh (Ctrl+F5 / disable cache in devtools) after flashing this version — every load
  after that self-corrects.

### Changed
- **`ServoController` is now microsecond-native** — position is tracked in pulse width (the servo's
  native unit) for finer calibration than whole degrees; the Servo-test page still drives in degrees
  (derived). New API: `writeUs`, `jogUs`, `run(dir)`, `minUs`/`maxUs`; `GET /api/servo` gains `us` and
  `targetUs`. New REST: `POST /api/servo/{us,jog,run}` and the `/api/shutters/*` family
  (`add`/`remove`/`rename`/`channel`/`set-edge`/`save-fav`/`recall`).
- `FW_VERSION` → **0.2.2**.

## [0.2.1] — 2026-07-08

Servo-test speed control, so bench moves can run slow enough for real blind linkages.

### Added
- **Servo speed control (Servo test tab)** — a **Speed** slider (5–120 °/s in steps of 5)
  limits how fast the bench servo slews. Angle commands and presets now **ramp** to the target at the
  set rate instead of snapping (`ServoController` keeps a current/target pair and steps it every 20 ms
  servo frame); Sweep obeys the same limit. The setting is **persisted**
  (`AppConfig::servoSpeedDps`, NVS, default **25 °/s**).
  New REST: `POST /api/servo/speed?dps=N` (0 = Max); `GET /api/servo` gains `target`, `moving`,
  `speed`. Status line shows *moving → N°* during a slewed move, and **Detach / Stop sweep freeze the
  move where it is** — a safety win when a linkage binds mid-travel.
- **[docs/hardware-layout.md](docs/hardware-layout.md)** — physical build plan for the hub
  prototype on a solderable copper breadboard: plan-view component placement (socketed ESP32,
  screw-terminal power spur, JST-XH I2C connectors), rail assignments with track cuts/bridges,
  nylon-standoff mounting + drill plan for the raised modules (PCA9685, XL4015, PD trigger,
  VEML7700), cable loom with connector recommendations, and a build-order checklist. Key rule:
  servo current runs point-to-point in 18 AWG and never through breadboard strips.

### Changed
- `FW_VERSION` → **0.2.1**. Servo test page polls at 0.5 s while a move/sweep is in flight
  (1.5 s when idle).

## [0.2.0] — 2026-07-07

Web-UI rebuild: the device interface becomes a LittleFS single-page app (sidebar shell modelled on
HomeKey-ESP32) with a live log stream and MQTT / Home Assistant scaffolding. Runs on a bare ESP32.

### Added
- **LittleFS single-page web UI** — the interface moved out of embedded C++ strings into static
  assets (`firmware/data/{index.html,style.css,app.js}`) served from LittleFS, with a persistent
  **sidebar**: **Info · MQTT · Actions · System · OTA Update · Logs**. The firmware now exposes a
  JSON/REST API + a WebSocket; a tiny **embedded recovery page** still offers OTA if the filesystem
  image hasn't been flashed, so a device can't strand itself.
- **Live log stream (Logs page)** — every `LOG*` line lands in an in-RAM ring buffer and streams to
  the browser over **`/ws/logs`** (WebSocket). Level filter chips (E/W/I/D/V), a minimum-level
  selector, text search, auto-scroll, export, and clear. Captures boot sequence, WiFi events, and
  MQTT rx/tx. New `LOGD` / `LOGV` macros; `Diagnostics` gains a log ring buffer + sink.
- **MQTT + Home Assistant scaffold** — real broker connection (`knolleary/PubSubClient`) with
  configurable host/port/client-ID/credentials/base-topic and a **HA MQTT Discovery** toggle, all
  persisted in NVS (`AppConfig::setMqtt`). Publishes hub availability (LWT) and **HA discovery for
  diagnostic sensors** (WiFi signal, uptime) so the device appears in Home Assistant. Per-shutter
  `cover` entities + command handling are Phase 4 (see below). `GET/POST /api/mqtt`.
- **System page** — a single **Quick Actions** card (Reboot · Reset WiFi · Reset config) plus
  **Device / WiFi / HomeKit / Security** sub-tabs. WiFi provisioning (scan/connect) moved here from
  the standalone `/wifi` page. **Security** adds a **web-authentication** toggle (HTTP basic auth,
  `AppConfig::setAuth`) guarding the UI + API; HTTPS shown as planned/disabled. **Reset config**
  factory-resets app settings while keeping WiFi credentials.
- **OTA page** — device-info strip, Firmware + LittleFS uploaders with an upload log, and a **Reboot**
  control (a firmware flash reboots automatically; a LittleFS flash needs a manual reboot to apply, so
  the button highlights after a filesystem upload).
- REST surface: `GET /api/info` (dashboard), `GET/POST /api/mqtt`, `GET/POST /api/auth`,
  `POST /api/system/{reboot,reset-wifi,reset-config}`; existing `/api/wifi/*`, `/api/servo/*`,
  `/api/ota` retained.

### Changed
- `FW_VERSION` → **0.2.0**. New deps: `PubSubClient` (+ `MQTT_MAX_PACKET_SIZE=1024`). LittleFS is
  mounted at boot (`LittleFS.begin(true)`); `Mqtt::loop()` is pumped from the main loop.
- **Reset/Reboot no longer sit in a per-tab footer** — they are consolidated into the System page's
  Quick Actions card (ADR-driven "one page only" decision).
- MQTT command structure + config ownership for Home Assistant locked in **ADR 0005** — browser-owned
  config, manual servo inventory, named **Daylight/Privacy** favourites, incremental jog for Up/Down.

### Migration
- **Flash the LittleFS image** (`-t buildfs` → `littlefs.bin`) with this firmware. Without it the
  device serves the recovery page (firmware/filesystem upload only).

## [0.1.0] — 2026-07-07

First hardware-phase release: single-servo bench test on top of the v0.0.3 skeleton.

### Added
- **Servo test tab (Phase 1)** — a new **Servo test** tab in the device web UI drives **one servo
  directly from an ESP32 GPIO** for hardware bring-up, before the PCA9685 / power chain exist. Signal
  pin defaults to **GPIO13** and is **changeable + persisted** (`AppConfig::servoPin`, NVS). Controls:
  set/validate the signal pin (rejects input-only/flash pins, flags strapping pins), a **0–180° angle
  slider**, **Min / Centre / Max** presets, a non-blocking **Sweep** toggle, and **Attach / Detach
  (release)**. Live status shows pin, attached/sweeping state, angle, and pulse width. The servo stays
  **detached at boot** so nothing moves until you act.
- **`ServoController`** promoted from stub to a real single-servo bench driver
  (`madhephaestus/ESP32Servo`, LEDC-backed; 50 Hz, 500–2500 µs). REST: `GET /api/servo`,
  `POST /api/servo/{pin,write,attach,detach,sweep}`.

### Changed
- `FW_VERSION` bumped to **0.1.0** (Phase 1 servo work).

## [0.0.3] — 2026-07-07

Web-UI refinement on top of v0.0.2.

### Added
- **Dedicated "Change network" page** (`/wifi`) — the WiFi section now has a single **Change network**
  button that opens its own page with the scan → select → password → **Set** flow and a **Back** link,
  instead of doing it inline.
- **Reset** and **Reboot** buttons pinned to the **bottom of the page** (below the tabs), each with a
  confirmation prompt. **Reset** forgets WiFi and restarts into the setup portal; **Reboot** restarts.
- **Three explicit firmware actions** on the Firmware tab — **Flash firmware**, **Flash LittleFS**, and
  **Flash both** (filesystem first, then firmware) — replacing the single auto-detecting button.

### Removed
- **Management access-point toggle** and the inline **Re-run setup** button (the "hub mode" idea) —
  along with the `apEnabled` setting, `/ap` route, `WiFiSetup::setSoftAP()`, and `ap_enabled` in
  `/info`. WiFi is changed in-browser; first-time setup still uses the portal, and **Reset** remains
  as the portal fallback.

## [0.0.2] — 2026-07-07

Skeleton completion on top of v0.0.1.

### Added
- **Tabbed device web UI** — three tabs: **System** — a **WiFi** section (network, IP, MAC, signal,
  access-point state, in-browser network picker + access-point toggle + Re-run setup) and a
  **System** section (device name,
  firmware version, hostname, uptime, boot count, free heap, last-restart reason, **Restart hub**,
  `/info`); **Firmware** (custom OTA, below); and **Apple Home** (blank placeholder for the Phase 5
  HomeKit UI).
- **Custom OTA page** (replaces ElegantOTA; mirrors HomeKey-ESP32's dual-target updater) — shows the
  installed firmware version, takes a **firmware** image and a **filesystem (LittleFS)** image in
  separate pickers, and flashes either independently or **both together** (filesystem first, then
  firmware, which reboots). Records the **last flash** — target, result, and UTC time (NTP) — shown
  on the page and in `/info`. Uploads stream through the core `Update` library; the ElegantOTA
  dependency is dropped.
- **`AppConfig`** — NVS/Preferences settings store (device name, boot count, AP-enabled flag) that
  survives OTA; the home for future shutter/HomeKit/MQTT settings.
- **`Diagnostics`** — structured serial logging (`LOGI/LOGW/LOGE`), a `/info` JSON endpoint
  (firmware, uptime, heap, reset reason, boot count, `ap_enabled`, WiFi), and a Reboot control.
- **In-browser WiFi change** — the WiFi section scans for nearby networks and lets you pick an SSID
  + password and **switch live, no reboot** (`GET /api/wifi/scan`, `POST /api/wifi/connect`). A wrong
  password reverts to the current network so you're never stranded. A **Re-run setup** fallback
  reboots into the setup portal for moving to a network you can't reach in-browser; first-time
  provisioning still uses the WiFiManager portal. (Replaces the earlier reboot-to-portal "Change
  WiFi" button.)
- **Management access point toggle** — the `Shutter-Hub-Setup` AP is explicitly torn down once WiFi
  is provisioned. A persisted setting (default **off**) plus a WiFi-section button can re-enable it
  as a management AP reachable at `192.168.4.1` — it serves the normal web UI and does **not**
  relaunch the setup portal.
- **Modular firmware layout** — `main.cpp` reduced to a thin entry point; real modules
  `AppConfig` / `Diagnostics` / `WiFiSetup` / `WebUI` / `Ota`, plus empty `begin()` stubs for
  `ServoController` (Phase 1/2), `Mqtt` (Phase 4), `HomeKit` (Phase 5), `LightSensor` (Phase 6).

### Changed
- Captive-portal responsiveness: disable WiFi modem power-save (`WiFi.setSleep(false)`), fixed AP
  channel, weak-AP filtering, and a "scanning takes a few seconds" note on the portal menu.
- Builds are ESP32-D only for now (`default_envs = esp32dev`); the ESP32-C3 target is deferred.

## [0.0.1] — 2026-07-07

First tagged release: documentation baseline + a buildable firmware framework with OTA.

### Added
- **Firmware framework scaffold (v0.0.1)** — first buildable ESP32 firmware (`firmware/`):
  PlatformIO project (Arduino Core) advertising `shutter-hub.local` over mDNS, serving a status
  page, and accepting browser OTA updates at `/update` (ElegantOTA + ESPAsyncWebServer). Runs on a
  bare ESP32 — no servo/PCA9685 hardware.
- **On-device WiFi provisioning** (WiFiManager) — first boot raises a `Shutter-Hub-Setup` access
  point with a captive portal; credentials are stored in NVS and **survive OTA updates**. No WiFi
  credentials are compiled into the binary (mirrors the HomeKey-ESP32 SoftAP + captive-portal
  pattern; pulled forward from Phase 3). A "Change WiFi" control clears saved creds and reopens the
  portal.
- Two board targets: `esp32dev` (ESP32-D, primary/locked board) and `esp32-c3-devkitm-1`
  (ESP32-C3). Each produces a merged full-flash image (one-time USB flash at `0x0`) and an
  app-only OTA bin; all four land in `firmware/dist/`. Releases ship both boards' bins + source.
- Master engineering brief consolidating all design discussion (`docs/project-brief.md`).
- Phased roadmap with status table and open decisions (`docs/project-plan.md`).
- Architecture notes and trade-off table (`docs/architecture.md`).
- Bill of materials, shutter facts, and power budget (`docs/inventory.md`).
- Cold-start map for future AI sessions (`docs/ai-context.md`).
- ADRs: 0001 hub vs independent nodes, 0002 servo = MG90D, 0003 power chain (XL4015) + PCA9685,
  0004 custom firmware vs ESPHome (with HomeKey-ESP32 reference).
- SVG diagrams: system architecture, power/wiring schematic, actuator linkage geometry
  (`docs/diagrams/`), embedded in the README.
- `hardware/` (KiCad schematic/PCB) and `cad/` (3D-printer source + STL/STEP) folders with READMEs.
- MIT `LICENSE` and `.gitignore`.

### Design decisions (locked)
- **Architecture:** central Shutter Hub + variable MG90D actuator modules (not 4 independent ESP32s).
- **Servo:** MG90D digital metal-gear micro servo.
- **Power:** USB-C PD → AITRIP trigger (12 V) → XL4015 @ 5.1 V (replaces LM2596), 1000–2200 µF cap.
- **Driver:** PCA9685 16-ch I2C, sharing the bus with a VEML7700 light sensor.
- **Linkage:** M2 × 50 mm ball-link pushrod; adjustable horn/arm ratios.
- **Firmware:** custom Arduino (HomeSpan + MQTT), not ESPHome.

### Notes
- OTA-first reordering: the web-server + ElegantOTA stack **and** the WiFiManager captive-portal
  provisioning were pulled forward from Phase 3 into a standalone "Phase S" scaffold, so every later
  phase flashes over WiFi instead of USB and no credentials ever live in the binary.
- No servo/sensor hardware built yet — the firmware runs on a bare ESP32 dev board.

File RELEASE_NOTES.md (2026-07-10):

# v0.7.2 — Dashboard pairing status + C3 GPIO safety

Two small, safe fixes on top of [v0.7.1](https://github.com/rhamblen/esp32-shutter-hub/releases/tag/v0.7.1).
The web UI is unchanged, so from v0.7.x this is a **firmware-only OTA**.

## What's new since v0.7.1

- **Fixed: the dashboard showed "not paired" when HomeKit *was* paired.** The status came from a
  transient flag that's only set when a pairing *event* fires — so after a reboot or an OTA (pairing
  survives both in NVS) it read false even though Apple Home was still connected. It now reads the
  actual controller list, so it's correct after any restart.
- **ESP32-C3 GPIO safety.** The servo/I²C pin whitelist was the ESP32-D map hard-coded for every chip;
  on a C3 it accepted pins that don't exist and, worse, the **SPI-flash pins (GPIO12–17) whose use
  bricks boot**. It's now chip-aware — the C3 build offers only `{0–10, 18–21}` and refuses the flash
  pins. (The C3 remains an untested engineering build in other respects — see below.)

No behavioural change on the ESP32-D beyond the corrected pairing label. Full detail in
[CHANGELOG.md](CHANGELOG.md).

## Download

All four variants are attached. The LittleFS image is the same for every variant — attached under both
board names so each variant has a matching filename.

| File | Use |
| ---- | --- |
| `shutter-hub-esp32d-pca9685-full-v0.7.2.bin` | First USB flash — ESP32-D, PCA9685 (I2C multi-channel), at `0x0` |
| `shutter-hub-esp32d-pca9685-ota-v0.7.2.bin`  | Firmware OTA — ESP32-D, PCA9685 |
| `shutter-hub-esp32d-direct-full-v0.7.2.bin`  | First USB flash — ESP32-D, direct-GPIO (single bench servo), at `0x0` |
| `shutter-hub-esp32d-direct-ota-v0.7.2.bin` | Firmware OTA — ESP32-D, direct-GPIO |
| `shutter-hub-esp32c3-pca9685-full-v0.7.2.bin`| First USB flash — ESP32-C3, PCA9685, at `0x0` *(untested)* |
| `shutter-hub-esp32c3-pca9685-ota-v0.7.2.bin` | Firmware OTA — ESP32-C3, PCA9685 *(untested)* |
| `shutter-hub-esp32c3-direct-full-v0.7.2.bin` | First USB flash — ESP32-C3, direct-GPIO, at `0x0` *(untested)* |
| `shutter-hub-esp32c3-direct-ota-v0.7.2.bin`  | Firmware OTA — ESP32-C3, direct-GPIO *(untested)* |
| `shutter-hub-esp32d-littlefs-v0.7.2.bin` | Filesystem image (web UI) — for the ESP32-D variants |
| `shutter-hub-esp32c3-littlefs-v0.7.2.bin` | Filesystem image (web UI) — for the ESP32-C3 variants (identical to the ESP32-D image) |

> **The ESP32-C3 bins are untested engineering builds** — they compile and carry the HomeKit fix, and
> the GPIO whitelist can no longer brick the board, but the C3 pinout/servo count/solar bus still need
> real-hardware verification ([docs/pinout.md](docs/pinout.md)). Use the ESP32-D (WROOM) builds for
> real hardware.

## Flash it

- **From v0.7.x:** the web UI is unchanged, so a firmware-only OTA (`…-ota-…`) is enough.
- **USB (first time):** flash the `…-full-…` image for your board at offset `0x0`, then upload the
  `…-littlefs-…` image via the web UI's OTA page.
- **Pairing:** enable HomeKit on System ▸ HomeKit, reboot, then add the accessory in Apple Home with
  the code shown on that tab. The bins carry no WiFi credentials (`Shutter-Hub-Setup` captive portal).

## Build from source

PlatformIO in [firmware/](firmware/): `pio run -e esp32d-pca9685` (or `-e esp32d-direct`), filesystem
with `-t buildfs`. The HomeSpan `%m` patch is applied automatically by `patches/apply_patches.py`.
ESP32-C3 variants compile but are deferred and untested.

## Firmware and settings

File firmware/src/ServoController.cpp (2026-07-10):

#include "ServoController.h"
#include "AppConfig.h"
#include "Diagnostics.h"

// Multi-slot µs driver. Position is tracked in MICROSECONDS (pulse width) — the
// servo's native unit — so blind calibration can land a slat far more finely than
// whole degrees. The Servo-test page still talks in degrees; those are derived
// from µs on the way in/out.
//
// v0.4.0 (ADR 0010): each physical output ("slot") carries its OWN slew state, so
// several shutters can move simultaneously — an HA "close all" slews every
// commanded channel at once. The PCA9685 generates all 16 waveforms autonomously
// in hardware; the loop() below just nudges each moving channel's pulse width
// once per 50 Hz frame (a few short I2C writes — trivial bus load). The bench
// API (writeUs, jog, run, sweep, attach…) acts on the ACTIVE slot only.
//
// The hardware layer is selected at build time (see platformio.ini / ADR 0008):
//   USE_PCA9685=0  ESP32Servo on a signal GPIO (LEDC-backed) — one slot.
//   USE_PCA9685=1  Adafruit PWM driver on PCA9685 channels over I2C — 16 slots.
// All slots stay DETACHED at boot so nothing twitches until something commands a
// move — this also dodges the attach-time current surge on a bare/USB-powered board.

#ifndef USE_PCA9685
#define USE_PCA9685 0
#endif

#if USE_PCA9685
  #include <Wire.h>
  #include <Adafruit_PWMServoDriver.h>
#else
  #include <ESP32Servo.h>
#endif

namespace {
// MG90-class pulse envelope. Wider than the classic 1000–2000 µs so the endpoints
// reach the servo's real mechanical limits during calibration.
const int      MIN_US          = 500;
const int      MAX_US          = 2500;
const uint32_t MOVE_TICK_MS    = 20;   // one 50 Hz servo frame
const uint16_t SWEEP_DPS_UNCAP = 133;  // sweep rate used when speed is "Max"
const uint32_t POS_PERSIST_MS  = 3000; // idle hold-off before writing a settled position (flash wear)

// Assembly "home": where an un-driven slot is assumed to rest after a factory-fresh boot,
// so the very first move slews from a real reference instead of snapping. Fit the servo horn
// / linkage with the arm parked HERE (slat closed) during the build. See ADR 0009.
const int HOME_US = MIN_US;

// One degree spans this many µs across the 0–180° / MIN..MAX map — used to turn
// the deg/s speed limit into a µs/s slew rate.
const float US_PER_DEG = (float)(MAX_US - MIN_US) / 180.0f;

#if USE_PCA9685
const int NSLOTS = 16;
#else
const int NSLOTS = 1;
#endif

// Per-slot slew state — one entry per physical output.
struct SlotState {
  float    cur       = (float)HOME_US;  // pulse width on the output right now
  int      tgt       = HOME_US;         // pulse width we're slewing toward
  bool     live      = false;           // attached / emitting pulses?
  bool     moving    = false;           // was mid-slew last tick (settle-edge detect)
  bool     dirty     = false;           // settled position awaiting NVS write
  uint32_t settledMs = 0;               // when it settled (debounce persistence)
};
SlotState g_s[NSLOTS];

uint16_t g_speed    = 25;              // max slew rate in deg/s; 0 = unlimited (snap)
bool     g_sweep    = false;           // bench sweep — active slot only
uint32_t g_lastTick = 0;

int   angleToUs(int a) { return map(constrain(a, 0, 180), 0, 180, MIN_US, MAX_US); }
int   usToAngle(int u) { return map(constrain(u, MIN_US, MAX_US), MIN_US, MAX_US, 0, 180); }
int   clampUs(int u)   { return constrain(u, MIN_US, MAX_US); }
int   clampSlot(int s) { return constrain(s, 0, NSLOTS - 1); }

// A GPIO that can act as a servo signal / I2C line on this board. Chip-aware at compile time so the
// ESP32-C3 builds can't offer a pin that doesn't exist — or, worse, a SPI-flash pin that HANGS/BRICKS
// the board when driven. Reused to validate the PCA9685 I2C SDA/SCL pins (I2C needs bidi-capable pins).
bool validGpio(uint8_t g) {
#if defined(CONFIG_IDF_TARGET_ESP32C3)
  // ESP32-C3 has GPIO0–21. Exclude 11 (VDD_SPI) and 12–17 (SPI flash) — driving those bricks boot.
  // 18/19 (USB) and 20/21 (UART0) are allowed but will disturb USB-JTAG / the serial console.
  static const uint8_t ok[] = {0,1,2,3,4,5,6,7,8,9,10,18,19,20,21};
#else
  // ESP32-D (WROOM): excludes input-only 34–39, flash 6–11 and non-existent pins.
  static const uint8_t ok[] = {0,1,2,3,4,5,12,13,14,15,16,17,18,19,21,22,23,25,26,27,32,33};
#endif
  for (uint8_t p : ok) if (p == g) return true;
  return false;
}

// ---- Backend: hardware primitives (all slot-addressed) ----------------------
#if USE_PCA9685
Adafruit_PWMServoDriver g_pwm(0x40);   // default I2C address (ADR 0003)
uint8_t g_ch  = 0;                     // ACTIVE test slot (Servo-test / calibration focus)
uint8_t g_sda = 21, g_scl = 22;        // I2C bus pins

void hwInit() {
  Wire.begin(g_sda, g_scl);
  g_pwm.begin();
  g_pwm.setOscillatorFrequency(27000000);  // datasheet internal osc — trims writeMicroseconds accuracy
  g_pwm.setPWMFreq(50);                     // standard analog-servo frame rate
}
void hwWrite(int slot, int us) { g_pwm.writeMicroseconds(slot, us); }
void hwAttach(int slot)        { g_s[slot].live = true; }   // channel goes live on the next write
void hwDetach(int slot) {
  g_pwm.setPWM(slot, 0, 4096);   // full-OFF — releases the servo (no holding torque)
  g_s[slot].live = false;
}
int  activeSlot() { return g_ch; }
#else
Servo   g_servo;
uint8_t g_pin = 13;               // signal GPIO

void hwInit() {
  // ESP32Servo shares the four LEDC hardware timers; hand them over up front.
  ESP32PWM::allocateTimer(0);
  ESP32PWM::allocateTimer(1);
  ESP32PWM::allocateTimer(2);
  ESP32PWM::allocateTimer(3);
}
void hwWrite(int, int us) { g_servo.writeMicroseconds(us); }
void hwAttach(int) {
  if (!g_servo.attached()) {
    g_servo.setPeriodHertz(50);            // standard analog-servo frame rate
    g_servo.attach(g_pin, MIN_US, MAX_US);
  }
  g_s[0].live = true;
}
void hwDetach(int) {
  if (g_servo.attached()) g_servo.detach();
  g_s[0].live = false;
}
int  activeSlot() { return 0; }
#endif

// Record where a slot just settled so a warm reboot restores it (and the first move
// slews from that reference instead of a guess). RAM first; the NVS write is debounced
// in loop() to spare the flash during calibration jogging.
void rememberPos(int slot) { g_s[slot].dirty = true; g_s[slot].settledMs = millis(); }
void persistPos(int slot) {
  AppConfig::setServoPos(slot, (int)roundf(g_s[slot].cur));
  g_s[slot].dirty = false;
}

// Point a slot at an absolute pulse width, honouring the speed limit.
void moveToUs(int slot, int us) {
  slot = clampSlot(slot);
  if (slot == activeSlot()) g_sweep = false;   // a direct move cancels a bench sweep
  SlotState &S = g_s[slot];
  S.tgt = clampUs(us);
  hwAttach(slot);
  if (g_speed == 0) {                          // Max speed — snap straight there
    S.cur = (float)S.tgt;
    hwWrite(slot, S.tgt);
    rememberPos(slot);                         // slewed moves are remembered on settle in loop()
  }                                            // otherwise loop() slews there at g_speed
}
}  // namespace

namespace ServoController {

void begin() {
  g_speed = AppConfig::servoSpeedDps();
#if USE_PCA9685
  g_sda = AppConfig::i2cSda();
  g_scl = AppConfig::i2cScl();
  g_ch  = AppConfig::servoChannel();
#else
  g_pin = AppConfig::servoPin();
#endif
  // Restore each slot's last-known position (or assembly HOME if never driven) so
  // the first move after a warm reboot / OTA slews from where the servo actually is.
  for (int i = 0; i < NSLOTS; i++) {
    int p = AppConfig::servoPos(i);
    g_s[i].cur = (p < 0) ? (float)HOME_US : (float)p;
    g_s[i].tgt = (int)roundf(g_s[i].cur);
  }
  hwInit();
#if USE_PCA9685
  LOGI("servo", "driver ready — PCA9685 @0x40, SDA GPIO%u/SCL GPIO%u, 16 slots, test channel %u @ %d µs, all detached (idle)",
       g_sda, g_scl, g_ch, (int)roundf(g_s[g_ch].cur));
#else
  LOGI("servo", "driver ready — direct GPIO%u @ %d µs, detached (idle)", g_pin, (int)roundf(g_s[0].cur));
#endif
}

bool        usesPca() { return USE_PCA9685; }
const char *backend() { return USE_PCA9685 ? "pca9685" : "gpio"; }

bool isValidPin(uint8_t g) { return validGpio(g); }

#if USE_PCA9685
uint8_t pin()     { return g_ch; }          // no signal GPIO on this build; report the channel
bool    setPin(uint8_t) { return false; }   // use setChannel() on a PCA9685 build

uint8_t channel() { return g_ch; }

bool setChannel(uint8_t ch) {
  if (ch > 15) { LOGW("servo", "rejected channel %u (0–15 only)", ch); return false; }
  if (ch == g_ch) return true;
  // Just move the test focus — never drive or release a channel on selection. With
  // per-slot state (ADR 0010) an in-flight move on the old channel keeps slewing to
  // completion; each channel keeps holding its own position.
  g_sweep = false;                           // the bench sweep doesn't follow a focus change
  g_ch = ch;
  AppConfig::setServoChannel(ch);
  LOGD("servo", "test focus → channel %u (at %d µs%s)", g_ch, (int)roundf(g_s[g_ch].cur),
       g_s[g_ch].moving ? ", mid-move" : "");
  return true;
}

uint8_t sdaPin() { return g_sda; }
uint8_t sclPin() { return g_scl; }

bool setI2cPins(uint8_t sda, uint8_t scl) {
  if (!validGpio(sda) || !validGpio(scl) || sda == scl) {
    LOGW("servo", "rejected I2C pins SDA%u/SCL%u", sda, scl); return false;
  }
  g_sweep = false;
  Wire.end();
  g_sda = sda; g_scl = scl;
  AppConfig::setI2cPins(sda, scl);
  hwInit();                                 // re-open the bus on the new pins
  for (int i = 0; i < NSLOTS; i++)          // re-assert every live output on the re-opened bus
    if (g_s[i].live) hwWrite(i, (int)roundf(g_s[i].cur));
  LOGI("servo", "I2C pins set to SDA GPIO%u / SCL GPIO%u", g_sda, g_scl);
  return true;
}
#else
uint8_t pin() { return g_pin; }

bool setPin(uint8_t g) {
  if (!isValidPin(g)) { LOGW("servo", "rejected GPIO%u (not output-capable)", g); return false; }
  bool wasAttached = g_servo.attached();
  g_sweep = false;
  if (wasAttached) g_servo.detach();
  g_pin = g;
  AppConfig::setServoPin(g);
  if (wasAttached) { hwAttach(0); g_servo.writeMicroseconds((int)roundf(g_s[0].cur)); }
  LOGI("servo", "signal pin set to GPIO%u", g_pin);
  return true;
}

// PCA9685-only accessors — harmless no-ops on a direct-GPIO build.
uint8_t channel()                  { return 0; }
bool    setChannel(uint8_t)        { return false; }
uint8_t sdaPin()                   { return 255; }
uint8_t sclPin()                   { return 255; }
bool    setI2cPins(uint8_t, uint8_t) { return false; }
#endif

bool attach() {
  int s = activeSlot();
  hwAttach(s);
  g_s[s].tgt = (int)roundf(g_s[s].cur);   // hold position — no surprise move on attach
  hwWrite(s, g_s[s].tgt);
  LOGD("servo", "attached at %d µs", g_s[s].tgt);
  return g_s[s].live;
}

void detach() {
  int s = activeSlot();
  g_sweep = false;
  g_s[s].tgt = (int)roundf(g_s[s].cur);   // freeze any in-flight move where it stopped
  hwDetach(s);
  rememberPos(s); persistPos(s);          // a deliberate stop — save the frozen position now
  LOGD("servo", "detached (released) at %d µs", (int)roundf(g_s[s].cur));
}

bool attached() { return g_s[activeSlot()].live; }

void writeAngle(int deg) { moveToUs(activeSlot(), angleToUs(constrain(deg, 0, 180))); }
void writeUs(int us)     { moveToUs(activeSlot(), us); }

void jogUs(int deltaUs) {
  // Nudge relative to the current target so repeated clicks accumulate cleanly,
  // even if a slew is still settling from the last one.
  int s = activeSlot();
  moveToUs(s, g_s[s].tgt + deltaUs);
}

void run(int dir) {
  int s = activeSlot();
  if      (dir > 0) moveToUs(s, MAX_US);       // slow-open toward the max endpoint
  else if (dir < 0) moveToUs(s, MIN_US);       // slow-close toward the min endpoint
  else { g_sweep = false; g_s[s].tgt = (int)roundf(g_s[s].cur); }  // stop where we are
}

int angle()        { return usToAngle((int)roundf(g_s[activeSlot()].cur)); }
int microseconds() { return (int)roundf(g_s[activeSlot()].cur); }
int minUs()        { return MIN_US; }
int maxUs()        { return MAX_US; }

uint16_t speed() { return g_speed; }

void setSpeed(uint16_t dps) {
  g_speed = (dps > 1000) ? 1000 : dps;
  AppConfig::setServoSpeedDps(g_speed);
  if (g_speed == 0) LOGI("servo", "speed set to Max (instant)");
  else              LOGI("servo", "speed set to %u deg/s", g_speed);
}

void startSweep() {
  int s = activeSlot();
  hwAttach(s);
  g_sweep = true;
  g_s[s].tgt = (g_s[s].cur < (MIN_US + MAX_US) / 2) ? MAX_US : MIN_US;
  LOGD("servo", "sweep started");
}

void stopSweep() {
  int s = activeSlot();
  g_sweep = false;
  g_s[s].tgt = (int)roundf(g_s[s].cur);   // stop where we are, not at the far end
  LOGD("servo", "sweep stopped");
}
bool sweeping()  { return g_sweep; }

// ---- Slot API (ADR 0010) -----------------------------------------------------

void moveSlotUs(uint8_t slot, int us) { moveToUs(slot, us); }

void stopSlot(uint8_t slot) {
  int s = clampSlot(slot);
  if (s == activeSlot()) g_sweep = false;
  g_s[s].tgt = (int)roundf(g_s[s].cur);   // freeze where it is (keeps holding torque)
}

int  slotUs(uint8_t slot)       { return (int)roundf(g_s[clampSlot(slot)].cur); }
int  slotTargetUs(uint8_t slot) { return g_s[clampSlot(slot)].tgt; }

bool slotMoving(uint8_t slot) {
  const SlotState &S = g_s[clampSlot(slot)];
  return S.live && abs((int)roundf(S.cur) - S.tgt) > 1;
}

void loop() {
  uint32_t now = millis();
  if (now - g_lastTick < MOVE_TICK_MS) return;
  float dt = (now - g_lastTick) / 1000.0f;
  g_lastTick = now;
  for (int i = 0; i < NSLOTS; i++) {
    SlotState &S = g_s[i];
    // Debounced write of a settled position (runs even while detached).
    if (S.dirty && (now - S.settledMs) > POS_PERSIST_MS) persistPos(i);
    if (!S.live) continue;
    bool sweepHere = g_sweep && i == activeSlot();
    if (sweepHere && fabsf(S.tgt - S.cur) < 1.0f)
      S.tgt = (S.tgt <= MIN_US) ? MAX_US : MIN_US;     // bounce off the ends
    if (fabsf(S.tgt - S.cur) < 0.5f) {                 // settled — nothing to do
      if (S.moving) { S.moving = false; rememberPos(i); }  // just arrived — remember where
      continue;
    }
    S.moving = true;
    // Slew toward the target in µs. deg/s → µs/s via US_PER_DEG. Sweeping at "Max"
    // uses a sane fixed rate instead of teleporting.
    float dps  = g_speed ? g_speed : (sweepHere ? SWEEP_DPS_UNCAP : 0);
    float step = dps ? dps * US_PER_DEG * dt : fabsf(S.tgt - S.cur);
    if (fabsf(S.tgt - S.cur) <= step) S.cur = S.tgt;
    else S.cur += (S.tgt > S.cur) ? step : -step;
    hwWrite(i, (int)roundf(S.cur));
  }
}

String statusJson() {
  const SlotState &S = g_s[activeSlot()];
  int curUs = (int)roundf(S.cur);
  bool moving = S.live && abs(curUs - S.tgt) > 1;
  String j = "{";
  j += "\"backend\":\""  + String(backend()) + "\"";
  j += ",\"usesPca\":"   + String(usesPca() ? "true" : "false");
  j += ",\"pin\":"       + String(pin());
  j += ",\"channel\":"   + String(channel());
  j += ",\"sda\":"       + String(sdaPin());
  j += ",\"scl\":"       + String(sclPin());
  j += ",\"attached\":"  + String(S.live ? "true" : "false");
  j += ",\"angle\":"     + String(usToAngle(curUs));
  j += ",\"target\":"    + String(usToAngle(S.tgt));
  j += ",\"us\":"        + String(curUs);
  j += ",\"targetUs\":"  + String(S.tgt);
  j += ",\"moving\":"    + String(moving ? "true" : "false");
  j += ",\"speed\":"     + String(g_speed);
  j += ",\"sweeping\":"  + String(g_sweep ? "true" : "false");
  j += ",\"min\":"       + String(MIN_US);
  j += ",\"max\":"       + String(MAX_US);
  j += "}";
  return j;
}

}  // namespace ServoController

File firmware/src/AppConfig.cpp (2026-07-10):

#include "AppConfig.h"
#include <Preferences.h>
#include <WiFi.h>

namespace {
Preferences prefs;
const char *NS = "shutterhub";
String   g_deviceName = "shutter-hub";
uint32_t g_bootCount  = 0;
String   g_lfType     = "none";
bool     g_lfOk       = false;
uint32_t g_lfEpoch    = 0;
uint8_t  g_servoPin   = 13;
uint16_t g_servoSpd   = 25;       // deg/s; 0 = unlimited
uint8_t  g_i2cSda     = 21;       // PCA9685 build: I2C SDA (ESP32-D default)
uint8_t  g_i2cScl     = 22;       // PCA9685 build: I2C SCL (ESP32-D default)
uint8_t  g_servoCh    = 0;        // PCA9685 build: channel driven by the Servo-test page

// MQTT / Home Assistant
bool     g_mqEn       = false;
String   g_mqHost     = "";
uint16_t g_mqPort     = 1883;
String   g_mqClient   = "";       // blank => derive from MAC
String   g_mqUser     = "";
String   g_mqPass     = "";
String   g_mqBase     = "shutter-hub";
bool     g_mqHaDisc   = true;

// HomeKit / Apple Home
bool     g_hkEn       = false;
String   g_hkName     = "";       // blank => fall back to the device name
String   g_hkCode     = "74888377";

// Light sensor + solar (Phase 6)
bool     g_lsEn       = false;
uint8_t  g_lsType     = 0;        // 0 = VEML7700, 1 = analog LDR (reserved)
uint8_t  g_lsBus      = AppConfig::BUS_DEDICATED;   // preference; clamped on 1-controller SoCs
uint8_t  g_lsSda      = 25;       // dedicated-bus SDA (distinct from the PCA9685's 21/22)
uint8_t  g_lsScl      = 26;       // dedicated-bus SCL
bool     g_solEn      = false;
uint32_t g_solTripLux = 60000;
uint16_t g_solTripS   = 600;      // 10 min
uint32_t g_solClrLux  = 30000;
uint16_t g_solClrS    = 1200;     // 20 min
uint8_t  g_solBright  = AppConfig::TGT_PRIVACY;
uint8_t  g_solClear   = AppConfig::TGT_NONE;

// Web auth
bool     g_authEn     = false;
String   g_authUser   = "admin";
String   g_authPass   = "";
}

namespace AppConfig {

void begin() {
  prefs.begin(NS, false);                       // read/write namespace
  g_deviceName = prefs.getString("devName", "shutter-hub");
  g_lfType     = prefs.getString("lfType", "none");
  g_lfOk       = prefs.getBool("lfOk", false);
  g_lfEpoch    = prefs.getUInt("lfEpoch", 0);
  g_servoPin   = prefs.getUChar("servoPin", 13);
  g_servoSpd   = prefs.getUShort("servoSpd", 25);
  g_i2cSda     = prefs.getUChar("i2cSda", 21);
  g_i2cScl     = prefs.getUChar("i2cScl", 22);
  g_servoCh    = prefs.getUChar("servoCh", 0);

  g_mqEn       = prefs.getBool("mqEn", false);
  g_mqHost     = prefs.getString("mqHost", "");
  g_mqPort     = prefs.getUShort("mqPort", 1883);
  g_mqClient   = prefs.getString("mqClient", "");
  g_mqUser     = prefs.getString("mqUser", "");
  g_mqPass     = prefs.getString("mqPass", "");
  g_mqBase     = prefs.getString("mqBase", "shutter-hub");
  g_mqHaDisc   = prefs.getBool("mqHaDisc", true);

  g_hkEn       = prefs.getBool("hkEn", false);
  g_hkName     = prefs.getString("hkName", "");
  g_hkCode     = prefs.getString("hkCode", "74888377");

  g_lsEn       = prefs.getBool("lsEn", false);
  g_lsType     = prefs.getUChar("lsType", 0);
  g_lsBus      = prefs.getUChar("lsBus", BUS_DEDICATED);
  g_lsSda      = prefs.getUChar("lsSda", 25);
  g_lsScl      = prefs.getUChar("lsScl", 26);
  g_solEn      = prefs.getBool("solEn", false);
  g_solTripLux = prefs.getUInt("solTripLux", 60000);
  g_solTripS   = prefs.getUShort("solTripS", 600);
  g_solClrLux  = prefs.getUInt("solClrLux", 30000);
  g_solClrS    = prefs.getUShort("solClrS", 1200);
  g_solBright  = prefs.getUChar("solBright", TGT_PRIVACY);
  g_solClear   = prefs.getUChar("solClear", TGT_NONE);

  g_authEn     = prefs.getBool("authEn", false);
  g_authUser   = prefs.getString("authUser", "admin");
  g_authPass   = prefs.getString("authPass", "");

  g_bootCount  = prefs.getUInt("bootCount", 0) + 1;
  prefs.putUInt("bootCount", g_bootCount);
}

String deviceName() { return g_deviceName; }

void setDeviceName(const String &name) {
  g_deviceName = name;
  prefs.putString("devName", name);
}

uint32_t bootCount() { return g_bootCount; }

uint8_t servoPin() { return g_servoPin; }

void setServoPin(uint8_t gpio) {
  g_servoPin = gpio;
  prefs.putUChar("servoPin", gpio);
}

uint16_t servoSpeedDps() { return g_servoSpd; }

void setServoSpeedDps(uint16_t dps) {
  g_servoSpd = dps;
  prefs.putUShort("servoSpd", dps);
}

uint8_t i2cSda() { return g_i2cSda; }
uint8_t i2cScl() { return g_i2cScl; }

void setI2cPins(uint8_t sda, uint8_t scl) {
  g_i2cSda = sda; g_i2cScl = scl;
  prefs.putUChar("i2cSda", sda);
  prefs.putUChar("i2cScl", scl);
}

uint8_t servoChannel() { return g_servoCh; }

void setServoChannel(uint8_t ch) {
  g_servoCh = ch;
  prefs.putUChar("servoCh", ch);
}

int servoPos(uint8_t slot) {
  if (slot > 15) return -1;
  char k[8]; snprintf(k, sizeof k, "svp%u", slot);
  return prefs.getInt(k, -1);                    // -1 => never stored (assume home)
}
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

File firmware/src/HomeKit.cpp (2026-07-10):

#include "HomeKit.h"
#include "AppConfig.h"
#include "Diagnostics.h"
#include "Shutters.h"
#include "ServoController.h"
#include <WiFi.h>
#include <ESPmDNS.h>
#include "HomeSpan.h"

// Phase 5 (v0.5.0): a HomeSpan bridge that mirrors the MQTT cover integration —
// one Apple Home "Window Covering" accessory per configured shutter, driving the
// same ServoController slots and reusing the same µs↔position maths (Mqtt.cpp).
// See HomeKit.h for the coexistence contract with WiFiManager / mDNS / the web server.

#ifndef FW_VERSION
#define FW_VERSION "0.0.0"
#endif

namespace {
bool          g_started      = false;   // bridge actually begun (enabled + set up)
volatile bool g_paired       = false;   // at least one controller paired (pair callback)
volatile bool g_resetPending = false;   // web UI asked to erase pairings
unsigned long g_resetAt      = 0;       // when to run it (lets the HTTP response flush)
volatile bool g_hapUp        = false;   // HomeSpan finished post-connect init (connect callback fired)
unsigned long g_hapWatchAt   = 0;       // when to WARN if the HAP server never came up
bool          g_hapWarned    = false;   // stall WARN already emitted?

// Strings handed to HomeSpan must outlive begin() — keep our own copies.
String g_bridgeName, g_code, g_ssid, g_psk, g_host;
String g_names[Shutters::MAX];

// ---- Position maths — same model as the MQTT cover (0 % = closed unless inverted).
// Kept local, mirroring Mqtt.cpp's copy, so HomeKit and MQTT report identically.
//
// MVP (owner request): a shutter must be *operable* from Apple Home even before it's
// calibrated — HomeKit is for driving blinds, not configuring them. So when an edge
// isn't calibrated we substitute the servo's pulse envelope (min = closed, max = open),
// giving HomeKit a usable 0–100 % range out of the box. `calibrated` records the real
// state (for logging); `cal` just means "operable" (the two ends differ).
struct ShInfo { uint8_t slot; bool cal; bool calibrated; bool inv; int openUs; int closedUs; };

ShInfo shInfo(int i) {
  ShInfo s;
  s.slot       = ServoController::usesPca() ? Shutters::channelAt(i) : 0;
  s.inv        = Shutters::invertedAt(i);
  String id    = Shutters::idAt(i);
  int op       = Shutters::edgeUs(id, true);
  int cl       = Shutters::edgeUs(id, false);
  s.calibrated = op != Shutters::UNSET && cl != Shutters::UNSET && op != cl;
  s.openUs     = (op != Shutters::UNSET) ? op : ServoController::maxUs();
  s.closedUs   = (cl != Shutters::UNSET) ? cl : ServoController::minUs();
  s.cal        = s.openUs != s.closedUs;      // operable as long as the ends differ
  return s;
}

int usToPct(const ShInfo &s, int us) {
  if (!s.cal) return 0;
  int pct = (int)lroundf(100.0f * (us - s.closedUs) / (float)(s.openUs - s.closedUs));
  if (s.inv) pct = 100 - pct;
  return constrain(pct, 0, 100);
}

int pctToUs(const ShInfo &s, int pct) {
  pct = constrain(pct, 0, 100);
  if (s.inv) pct = 100 - pct;
  return s.closedUs + (int)lroundf((s.openUs - s.closedUs) * pct / 100.0f);
}

// ---- One HomeKit Window Covering, bound to a shutter index --------------------
// HomeKit decides opening/closing/stopped purely by comparing CurrentPosition to
// TargetPosition, so there's no PositionState to maintain: update() drives the servo
// on a Home-app change; loop() streams the live position back and, once the slot has
// settled, syncs the target to the real position so moves made elsewhere (MQTT, the
// web UI) are reflected in Apple Home too.
struct DevShutter : Service::WindowCovering {
  int idx;
  uint8_t slot;
  SpanCharacteristic *current;
  SpanCharacteristic *target;

  DevShutter(int i) : Service::WindowCovering() {
    idx = i;
    ShInfo s = shInfo(i);
    slot = s.slot;
    int pct = usToPct(s, ServoController::slotUs(slot));
    current = new Characteristic::CurrentPosition(pct);
    target  = new Characteristic::TargetPosition(pct);
  }

  boolean update() override {
    ShInfo s = shInfo(idx);
    int tp   = target->getNewVal();
    if (!s.cal) {                         // degenerate (min==max) — nothing to drive
      LOGW("homekit", "%s: target %d%% ignored — no usable travel range",
           Shutters::idAt(idx).c_str(), tp);
      return false;                       // reject: Home app reverts the tile
    }
    int us = pctToUs(s, tp);
    LOGD("homekit", "%s: target %d%% -> %d us%s", Shutters::idAt(idx).c_str(), tp, us,
         s.calibrated ? "" : " (default envelope — not calibrated)");
    ServoController::moveSlotUs(slot, us);
    return true;
  }

  void loop() override {
    ShInfo s = shInfo(idx);
    int pct  = usToPct(s, ServoController::slotUs(slot));
    if (pct != current->getVal()) current->setVal(pct);
    // Once the servo has stopped, make HomeKit's target match reality so an
    // external move (MQTT/web UI) doesn't leave the tile showing a phantom motion.
    if (!ServoController::slotMoving(slot) && target->getVal() != pct) target->setVal(pct);
  }
};

// ---- HomeSpan callbacks ------------------------------------------------------
void onConnection(int count) {
  if (count) g_hapUp = true;            // reached the END of HomeSpan's post-connect init (HAP up)
  LOGI("homekit", "HomeSpan network %s", count ? "connected" : "disconnected");
}
void onPair(boolean isPaired) {
  g_paired = isPaired;
  LOGI("homekit", "%s", isPaired ? "paired with a controller" : "no controllers paired");
}
void onController() {
  LOGI("homekit", "controller list changed (%d paired)", HomeKit::controllers());
}
// Mirror HomeSpan's own state machine to the web Logs page (DEBUG) — handy for future HomeKit
// debugging without a USB serial cable: "Device not yet Paired" = up and discoverable, "Paired"
// once a controller completes pairing.
void onStatus(HS_STATUS s) {
  LOGD("homekit", "HomeSpan state: %s", homeSpan.statusString(s));
}
}  // namespace

namespace HomeKit {
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

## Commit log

2026-07-07 docs: initial project brief for ESP32 Smart Shutter Hub
    Consolidated design baseline for a hub-centric ESP32 shutter tilt system:
    master engineering brief, phased plan, architecture notes, inventory/BOM,
    AI cold-start map, and ADRs (hub topology, MG90D servo, XL4015+PCA9685 power
    chain, custom HomeSpan firmware vs ESPHome).
    Includes SVG diagrams (system architecture, wiring schematic, linkage geometry)
    and hardware/ + cad/ folders scaffolded for KiCad schematics and 3D-printer
    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
2026-07-07 docs: clarify shutter count is any number ≥ 1, not an enumerated set
2026-07-07 docs: fix linkage diagram legibility and correct slat-pivot mechanism
    - Redraw linkage-geometry.svg as two clear panels (servo leverage +
    side-view slat tilt) with larger, non-overlapping text.
    - Show slats pivoting about their centres with the tilt rod linked ahead
    of the pivot, correcting the earlier end-pivot impression.
    - Declutter wiring-schematic.svg: loads in one row on shared rails, bulk
    cap relocated, servo wiring shown once as xN, larger fonts.
    - Clarify the centre-pivot mechanism in project-brief.md.
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2026-07-07 feat(v0.0.2): complete firmware skeleton — tabbed UI, custom OTA, config, diagnostics
    Modular refactor of the v0.0.1 scaffold into the brief's module layout, plus:
    - Tabbed web UI: System (WiFi + System sections) / Firmware / Apple Home placeholder
    - In-browser WiFi picker (scan + switch live, revert on wrong password); Re-run
    setup fallback; management access-point toggle; setup AP torn down after provisioning
    - Custom firmware+LittleFS OTA (core Update.h) with version display and last-flash
    record (NTP time), replacing ElegantOTA
    - AppConfig (NVS settings) + Diagnostics (structured logging, /info JSON, reboot,
    reset reason); stubs for ServoController/Mqtt/HomeKit/LightSensor
    - ESP3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
    [AppConfig.cpp, HomeKit.cpp, LightSensor.cpp]
2026-07-07 feat(v0.0.3): dedicated Change-network page, bottom Reset/Reboot, 3-way OTA
    - Move "Change network" to its own /wifi page (scan -> select -> password -> Set,
    with a Back link); WiFi section just links to it
    - Add Reset and Reboot buttons at the bottom of every page, each with a confirm
    - Firmware tab: three explicit buttons (Flash firmware / Flash LittleFS / Flash both)
    - Drop the management access-point toggle + inline re-run-setup ("hub mode"): remove
    apEnabled setting, /ap route, WiFiSetup::setSoftAP, and ap_enabled in /info
    [AppConfig.cpp, WebUI.cpp, main.cpp]
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2026-07-08 feat(v0.2.1): LittleFS web UI + logs + MQTT/HA (v0.2.0 work) and servo speed control
    Rolls up the unreleased v0.2.0 rebuild and the v0.2.1 speed feature:
    v0.2.0 (never committed separately):
    - Web UI moves to a LittleFS SPA (sidebar: Info/MQTT/Actions/System/OTA/Logs)
    with an embedded recovery page fallback
    - Live log ring buffer + /ws/logs WebSocket stream with level filters
    - MQTT broker connection + HA discovery for diagnostic sensors (ADR 0005)
    - System page Quick Actions, web basic-auth toggle, OTA firmware+LittleFS page
    v0.2.1:
    - Servo test speed slider (5-120 deg/s step 5, default 25), persisted in NVS
    (AppConfig::servoSpeedDps); moves/presets/sweep slew at the set rate
    - POST /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
    [AppConfig.cpp, Mqtt.cpp, ServoController.cpp]
2026-07-08 feat(v0.2.2): Shutters calibration page + microsecond servo control
    Per-blind calibration (Phase 2): a dedicated Shutters page separate from the
    Servo-test bench diagnostic, backed by a microsecond-native ServoController
    and a new Shutters NVS module (name/channel/closed/open/Daylight/Privacy/
    invert per blind). Also fixes stale-web-UI caching after a filesystem reflash.
    [ServoController.cpp, WebUI.cpp, app.js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]
2026-07-08 docs(hardware-layout): add SVG diagrams; board-mount buck+driver, lid-mount light sensor
    Replace the ASCII layouts with five rendered SVG diagrams (overview, plan
    view, rail cuts/bridges, standoff elevation, cable loom). Update the mounting
    plan per build decisions: XL4015 and PCA9685 now fix to the breadboard on tall
    nylon standoff pillars (board is the chassis), and the VEML7700 mounts to the
    case lid on a detachable J3 lead so it reads true ambient light.
2026-07-08 feat(v0.3.0): build variants (board × servo backend) + PCA9685 servo driver
    The servo backend is now a compile-time choice, identified everywhere so an OTA
    image is never flashed onto the wrong topology.
    - platformio.ini: 4 variant envs (esp32d/esp32c3 × direct/pca9685) with FW_VARIANT
    ids; default esp32d-pca9685; add Adafruit PWM Servo Driver lib (pca builds only)
    - ServoController: compile-time backend (USE_PCA9685) — PCA9685 over I2C vs
    ESP32Servo — sharing one µs core; channel + I2C-pin addressing on pca builds
    - AppConfig: persist i2cSda/i2cScl/servoChannel (defaults 21/22/0)
    - WebUI: /api/info gains variant+backend; add /api/servo/channel + /api/servo/i2c
    - data/: runtime-a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
    [AppConfig.cpp, ServoController.cpp, WebUI.cpp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]
2026-07-08 fix(v0.3.0): controlled channel switching + per-shutter drive channel
    - ServoController (PCA9685): selecting a channel no longer drives the new channel
    to the previous channel's position at full speed, nor releases the old one. Each
    channel keeps its own remembered pulse width (g_chPos[16]); switching focus moves
    and releases nothing. Real moves still slew at the set speed.
    - Shutters UI: selecting a shutter (or reassigning its channel) now points the servo
    driver at that shutter's PCA9685 channel, so calibration/recall drive the right
    blind instead of whatever channel the Servo-test page last left active.
    [ServoController.cpp, app.js]
2026-07-08 feat(v0.3.0): servo position memory in NVS + assembly home convention
    Tackles the open-loop first-move jump: an unfed servo has no position, so its
    first pulse snaps the arm to the commanded value at full speed. Slewing only
    smooths a move whose start point is already ~correct — so make the assumed start
    match reality.
    - ServoController persists each drive slot's settled position to NVS and restores
    it on boot (direct = slot 0; PCA9685 = channel). Warm reboot/OTA (servos still
    powered) => restored == actual => first move slews, no snap. Writes debounced
    (~3s after settle, plus on detach and channel switch) to spare flash.
    - A never-driven slot defaults to HOME_US (min-µs "closed" e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
    [AppConfig.cpp, ServoController.cpp]
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2026-07-08 feat(v0.4.0): MQTT / Home Assistant covers — per-shutter cover+buttons, concurrent servo drive
    Phase 4: each shutter becomes an HA cover (open/close/stop + position 0-100,
    mapped through its own calibration) plus six buttons (jog, Daylight/Privacy
    recall + save) via MQTT discovery, with retained position/state publishing
    that also tracks web-UI moves. Discovery re-publishes on any shutter config
    change; deleted shutters are cleaned off the broker. ServoController gains
    per-slot slew state (ADR-0010) so commanded channels move simultaneously;
    switching the test channel no longer freezes an in-flight move. MQTT page
    Topics tab is now a live per-shutter topic map. Phase-4b calibration-card
    co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
    [Mqtt.cpp, ServoController.cpp, WebUI.cpp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]
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2026-07-09 feat(v0.4.2): Home Assistant operating card (Lovelace)
    Custom shutter-hub-card: 1-6 named shutters side by side with the four blind
    states (Open/Close/Daylight/Privacy) + a manual position slider + Stop, applied
    to all shutters or one selected shutter. Binds to the ADR-0005 MQTT-discovery
    cover + daylight/privacy button entities; plain custom element, no build step.
    Deployed to the My Home > Shutters dashboard as an inline module resource.
    Frontend only, no firmware change (no new bins). Calibration/config card and its
    firmware commands (goto_us, raw-us readback, save:open/close) stay documented as
    a future phase. New ADR-0007 + docs/ha-lovelace-card.md.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
2026-07-09 fix(ha-card): reorder state buttons to Close/Privacy/Daylight/Open
    Closed->open progression. Card-only; deployed inline resource updated in place.
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2026-07-09 feat(v0.4.4): System > HomeKit config tab + icons on the System sub-tabs
    Phase 5 groundwork, ahead of the HomeSpan bridge itself (v0.5.0):
    - System > HomeKit sub-tab: enable toggle, bridge name (defaults to device
    name), 8-digit setup code (default 748-88-377 = "SHUTTERS" on a keypad,
    distinct from HomeSpan's 466-37-726), random-code generator, pairing QR
    (X-HM:// payload, setup ID SHUT) via qrcode.min.js (qrcodejs 1.0.0, MIT).
    - /api/homekit GET/POST + /api/homekit/reset-pairings; config in NVS
    (AppConfig hkEnabled/hkBridgeName/hkSetupCode); Apple's trivial-code
    blocklist enforced device-side.
    - HomeKit stub gains running/paired/controllers/resetPairings so Phase 5
    only swaps th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
    [AppConfig.cpp, HomeKit.cpp, WebUI.cpp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]
2026-07-09 feat(v0.4.4): icons on the MQTT sub-tabs (Broker/Topics); skip SSL/TLS
    Extends the v0.4.4 tab-icon work to the MQTT sub-tab bar: globe (Broker),
    inbox (Topics), matching the System tab pattern. SSL/TLS was considered and
    deliberately dropped — the broker is local-LAN Mosquitto, so plaintext MQTT
    is the norm and on-device TLS isn't worth the cert-management / handshake-RAM
    cost. Filesystem-only change; littlefs bin refreshed, firmware bins unchanged.
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2026-07-09 fix(v0.5.0): correct stale HomeKit log/error copy that implied the bridge is unbuilt
    The /api/homekit save handler still logged "(bridge lands in v0.5.0)" and the
    reset-pairings 409 said the bridge "arrives with v0.5.0" — both false now that
    the bridge ships. The save log now reads "REBOOT to apply (bridge starts at
    boot)" and reset-pairings says the bridge "isn't running — enable it and reboot
    first". No behaviour change; regenerated dist bins.
    [WebUI.cpp]
2026-07-09 fix(v0.5.1): reliable reboot via esp_timer; decouple OTA flashing from restart
    Field-testing v0.5.0 showed the device frequently would not restart on command:
    OTA firmware flashes and the web Reboot buttons set a flag serviced by the Arduino
    loop(), so when the loop is starved/blocked the restart never fired — a freshly
    OTA-flashed image never ran until a physical power-cycle.
    - Diagnostics::scheduleReboot() restarts from a one-shot high-priority esp_timer,
    independent of loop(). /api/system/reboot, reset-wifi, reset-config now respond,
    do their NVS work inline, then schedule the restart. Removed the loop-serviced
    pendingReboot/pendingForget/pendingFactory flags.
    - OTA no longer aut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
    [WebUI.cpp, app.js]
2026-07-09 fix(v0.5.2): advertise _hap._tcp so the Home app can discover the bridge
    On hardware the bridge ran with the correct pairing code, but the iPhone never
    found it in Add Accessory (#1 = not discovered), so QR/manual pairing had nothing
    to attach to and no HAP logs appeared.
    Root cause: WebUI::begin() already calls MDNS.begin() for the _http service, so
    HomeSpan's own MDNS.begin() no-ops on the already-running responder and the
    _hap._tcp service is never announced. HomeKit::begin() now calls MDNS.end()
    immediately before homeSpan.begin() so HomeSpan initialises mDNS cleanly and
    advertises _hap; the _http service is re-added right after, so <name>.local keeps
    working. Both variants build; dist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
    [HomeKit.cpp]
2026-07-09 fix(v0.5.3): run HomeSpan on its own task so HAP never stalls the servo loop
    Confirmed by A/B test (v0.4.1 fine; v0.5.1 with HomeKit off fine): with the
    bridge enabled, servo control and Home Assistant/MQTT stopped working. Root
    cause was homeSpan.poll() being called from the Arduino loop(), sharing the one
    cooperative loop with ServoController::loop() (which writes each slewed servo
    frame to the PCA9685) and Mqtt::loop(). HAP/SRP work held the CPU long enough
    that servo frames and MQTT commands were never serviced.
    HomeSpan now runs on its own FreeRTOS task via homeSpan.autoPoll(16384, 1, 0)
    (16 KB stack for the SRP big-number math, core 0 alongside WiFi/AsyncTCP), so
    the main loop on core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
    [HomeKit.cpp]
2026-07-09 fix(v0.5.4): single mDNS owner — let HomeSpan advertise HAP so Home app can discover it
    The Home app still found nothing after v0.5.2. Compared against rednblkx/HomeKey-ESP32
    (a proven build that also runs HomeSpan + web server + MQTT): its web server never
    touches mDNS — HomeSpan is the sole owner. Ours had two initialisers of the one shared
    ESPmDNS responder (WebUI _http + HomeSpan _hap), leaving _hap._tcp unannounced.
    WebUI now skips MDNS.begin() when HomeKit is enabled and defers to HomeSpan (same
    hostname via setHostNameSuffix(""), so <name>.local still resolves; HomeKit::begin()
    re-adds _http under HomeSpan's responder). When HomeKit is off, WebUI owns mDNS as
    before. Dropped the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
    [HomeKit.cpp, WebUI.cpp]
2026-07-10 feat(v0.6.0): light sensor + solar heat protection (Phase 6)
    VEML7700 ambient-light sensor drives a trip/clear state machine that moves the
    shutters before the room bakes, and releases them when the sun passes.
    - LightSensor: real VEML7700 driver (was a stub) on its OWN I2C bus (Wire1,
    default SDA 25 / SCL 26, configurable). Lean vendored register driver, no new
    lib deps -- the HomeSpan build has no flash headroom for Adafruit's. Fixed
    gain 1/8 + IT 25ms, full scale ~120k lx, linear lux (no Vishay correction).
    - SolarLogic: idle -> counting-trip -> tripped -> counting-clear, with dwell
    timers providing hysteresis. Bright/clear targets are five-valued (open,
    closed, daylight, priva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
    [AppConfig.cpp, LightSensor.cpp, Mqtt.cpp]
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2026-07-10 docs: pinout page, GPIO defaults, fix stale shared-I2C-bus notes
    Add docs/pinout.md: the ESP32-D GPIO defaults the firmware actually ships
    (Wire SDA21/SCL22 -> PCA9685; Wire1 SDA25/SCL26 -> VEML7700; GPIO13 servo
    signal on -direct), the validGpio() whitelist and why 6-11 / 34-39 are
    refused, and a *proposed* ESP32-C3 map.
    Fix stale "shared I2C bus" prose that contradicted ADR 0011 and the shipped
    v0.6.0 firmware: project-brief.md claimed the PCA9685 and VEML7700 share one
    bus and omitted the sensor bus from its pinout table; architecture.md gave
    "shared I2C with sensor" as a reason to pick the PCA9685; project-plan.md D9
    referred to "the shared I2C bus". The diagrams were already correct.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
2026-07-10 feat(v0.6.1): make the sensor I2C bus a setting; solar works on the ESP32-C3
    v0.6.0 put the VEML7700 on a dedicated Wire1 so a damaged sensor lead could
    never wedge the servo bus (ADR 0011). Correct default -- but it made solar
    impossible on the ESP32-C3, which has one I2C controller (SOC_I2C_NUM == 1)
    to the ESP32-D's two. The Arduino core declares Wire1 unconditionally, so the
    C3 build linked cleanly and then Wire1.begin() returned ESP_ERR_INVALID_ARG at
    runtime: a permanent "not detected", indistinguishable from a wiring fault.
    The bus is now AppConfig::SensorBus, chosen on the Solar page:
    - BUS_DEDICATED (default) -- own Wire1 on lsSda/lsScl (25/26). Fault-isolated.
    - BUS_SHARED -- ride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
    [AppConfig.cpp, LightSensor.cpp, WebUI.cpp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]
2026-07-10 feat(v0.6.2): hardware & wiring table + HomeKit status on the Info page
    The Info page now carries a table naming every physical device, its I2C bus
    (shared or dedicated), its pins, and its address or PCA9685 channel, so a
    running hub's wiring can be checked against the board in one place. A
    direct-GPIO build shows the servo's signal pin and no channels; a PCA9685
    build shows the driver plus one row per shutter with its channel and
    calibration state. The light sensor row reports the pins ACTUALLY in use,
    after any clamp to the shared bus on a one-controller SoC.
    HomeKit joins MQTT in the Network & Services card, as disabled /
    enabled-pending-reboot / active / paired.
    GET /api/info gains `se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
    [LightSensor.cpp, Mqtt.cpp, WebUI.cpp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]
2026-07-10 docs: audit + correct published docs against v0.6.2 firmware
    Documentation-only pass; no code, behaviour, or version changes.
    - HomeKit: correct the pairing status everywhere to "built but unpaired,
    parked". project-plan claimed pairing was verified, contradicting README,
    installation and user-guide; the status table now shows Phase 5 ◐ with its
    exit criteria unmet.
    - Phase 6 marked ◐ (built, physical VEML7700 still unwired), not ☑.
    - Document the Lovelace card's solar keys (solar_switch/solar_lux/solar_state)
    in ha-card/README and ha-lovelace-card §2a, incl. the raw-lux vs display-only
    brightness-% distinction.
    - firmware/README brought to v0.6.2 (was v0.4.0): un-stub Home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
2026-07-10 feat(v0.7.0): HomeKit pairing works — fix newlib-nano %m sscanf hang in HomeSpan
    Root cause of the never-discoverable/never-pairable HomeKit bridge: HomeSpan
    1.9.1's Span::checkConnect() validates its mDNS hostname with
    sscanf(hostName,"%m[A-Za-z0-9-]",&d), and newlib-nano (this arduino-esp32
    toolchain) doesn't implement the %m allocating conversion — so the check falsely
    failed and HomeSpan hit its while(1) PROGRAM HALTED on the poll task, before it
    advertised _hap._tcp or opened port 1201. Not mDNS ownership, WiFi, or CPU core.
    - Vendored HomeSpan patch (firmware/patches/HomeSpan.cpp) + pre-build hook
    (patches/apply_patches.py via extra_scripts) re-applied to all variants.
    - mDNS in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
    [HomeKit.cpp, HomeSpan.cpp, Mqtt.cpp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]
2026-07-10 chore(v0.7.1): tidy up the v0.7.0 HomeKit fix — remove debug scaffolding, finish log levels
    No behavioural change. The %m HomeSpan patch, main-thread mDNS init, HAP-stall
    WARN watchdog and core-1 autoPoll all carry over unchanged.
    - Remove the [hs] breadcrumbs from patches/HomeSpan.cpp and the hsCrumb hook from
    HomeKit.cpp; the vendored patch is now the %m fix only.
    - Remove the [dbg] one-shot bridge summary + ping hint; keep the HomeSpan status
    callback as a clean DEBUG line ("HomeSpan state: …").
    - Log levels, second pass: per-action lines INFO -> DEBUG (MQTT cover commands +
    rx, servo attach/detach/test-focus/sweep, HomeKit per-move, solar counting/
    cancelled transitions). IN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
    [HomeKit.cpp, HomeSpan.cpp, Mqtt.cpp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]
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2026-07-10 fix(v0.7.2): correct paired-status after reboot + chip-aware servo GPIO whitelist
    - HomeKit::paired() now derives from the persisted controller list
    (controllers() > 0) instead of the transient g_paired event flag, which
    doesn't fire at boot — so the dashboard/HomeKit tab no longer reads "not
    paired" after a reboot or OTA when Apple Home is still connected.
    - ServoController::validGpio() is now #if CONFIG_IDF_TARGET_ESP32C3: the C3
    build offers only {0-10,18-21}, refusing GPIO12-17 (SPI flash → bricks boot)
    and non-existent pins, for both the servo signal pin and the PCA9685 I2C pins.
    Closes an ESP32-C3 bricking footgun. C3 remains an untested engineering build.
    Co-Authored-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
    [HomeKit.cpp, ServoController.cpp]
2026-07-10 docs: sweep documentation to reflect HomeKit + solar working (1.0 readiness)
    HomeKit pairing works (v0.7.0) and the solar/light-sensor feature is in place,
    so remove the "pairing doesn't work / parked" and "sensor not yet wired /
    unproven" framing across the docs and mark Phases 5 and 6 done.
    - project-plan: Phase 5 ☑ (pairing works, %m fix noted), Phase 6 ☑; status
    table + intro updated; v1.0.0 is now gated on Phase 7 (physical build-out).
    - README / firmware/README: current release v0.7.2; HomeKit + solar presented
    as working features.
    - ai-context: HomeKit section rewritten (works; %m root cause; main-thread mDNS;
    paired() reads NVS); flash figures refreshed.
    - user-guide / ins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
2026-07-10 docs(hardware): add ESP32-D KiCad schematic and visual wiring diagram
    - shutter-hub.kicad_sch: complete circuit with all components and connections
    - shutter-hub-schematic.svg: visual schematic showing power chain, loads, and wiring
    - Critical notes for breadboard build: XL4015 adjustment, pull-ups, bulk cap, decoupling
    Includes: USB-C → XL4015 (5.1V), ESP32-D, PCA9685 servo driver, VEML7700 sensor
    Two I2C buses: servo (GPIO21/22) and sensor (GPIO25/26)
    Ready for breadboard prototyping.
    [shutter-hub.kicad_sch]
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2026-07-11 docs(mechanical): correct tilt-rod kinematics; add interactive linkage design doc
    The hidden tilt rod translates on a 36mm arc (four-bar linkage), it does
    not twist like a venetian wand - the old 10mm:20mm horn/arm sizing could
    never have worked. New baseline: 25mm printed arm, 50mm hole-to-hole
    pushrod, servo axis (-8,-60) from the bottom slat pivot, ~140deg sweep
    for 90deg slat travel, worst-case torque ratio 0.78.
    docs/tilt-linkage-design.html is a self-contained interactive simulator +
    design doc (solver embedded); enter measured shutter dims and re-check
    clearance/torque flags before printing P1-P4.
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2026-07-11 docs(v0.9.1): front-edge hook baseline - pin swings 06:00->03:00, servo tucked under slat
    Owner correction: the hook grips the slat's FRONT edge, so the drive pin
    hangs straight down at closed and sweeps to horizontal (room side) at
    open - crank phase -180, not the v0.9.0 top-rear arc. Closure sense is
    unchanged. New solved baseline: pin 24mm on the front-edge line, stock
    20mm horn, M2x25 pushrod at 46mm h2h, servo axis (+32,-30) - in the
    corner under the bottom slat, 18mm behind the rail rear face, still
    fully hidden. ~114deg sweep, jam margin 11.3mm, ratio <=0.85.
    v0.9.0 documentation, drawing and simulator presets are retained; the
    simulator gains a 'v0.9.1 front-edge hook' preset (defau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
2026-07-11 cad(P2): slat-clip crank from owner's sleeve clip + drill boss; solved linkage numbers
    Reverse-engineered clip1.3mf: sleeve mouth 8.35mm wedging tight on the
    measured 8mm slat (taper is the retention); the 5mm fin jaw is the
    factory rod-bar catch, unused here. Added a solid drill boss (x46-62)
    under the bottom strap - drill O1.8 at 12mm from the seated rear edge
    for the M2 ball stud -> crank pin 26.6mm @ -16deg.
    Matching rear pull-down linkage (solved for this exact pin): stock 20mm
    horn, M2x35 pushrod at 58mm h2h, servo axis (+21,-49) on the rail rear
    face; ~129deg sweep for 90deg slat travel, jam margin 9.9mm, torque
    ratio <=0.79, envelope x[+7,+41] - fully hidden behind the panel.
    Co-Au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
    [slat-clip-crank.3mf]
2026-07-12 docs(v0.9.2): complete mechanical build package for the tilt actuator
    Settled, buildable design - the owner's real slat clip (fit confirmed on
    the 8mm slat) drives a fully hidden rear pull-down linkage through a
    tape-mounted servo cradle.
    - P2 slat-clip-crank.3mf moved from [Unreleased] into 0.9.2.
    - P1 servo cradle: tape-mount design + drawings (docs/diagrams/
    servo-cradle-p1.svg, design doc section 7). Case bonded in with a 2nd
    VHB strip, no screws, mounting tabs unused (side walls stop short so
    the tab flange sits proud); 4mm cable gallery with an open lay-in slot
    so the plug never threads through. 3MF to be cut on approval.
    - Build baseline finalised for the taped stack: axis (+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
2026-07-12 cad: add STL export + one-click download links for print files
    - Export slat-clip-crank.stl alongside the 3MF (identical geometry,
    1172 tris) for slicers/people who prefer STL.
    - Add a 'Download the 3D-print files' table with direct /raw/ links to
    README and cad/README so parts save without navigating the tree;
    part README gets the same links.
    [slat-clip-crank.stl]
